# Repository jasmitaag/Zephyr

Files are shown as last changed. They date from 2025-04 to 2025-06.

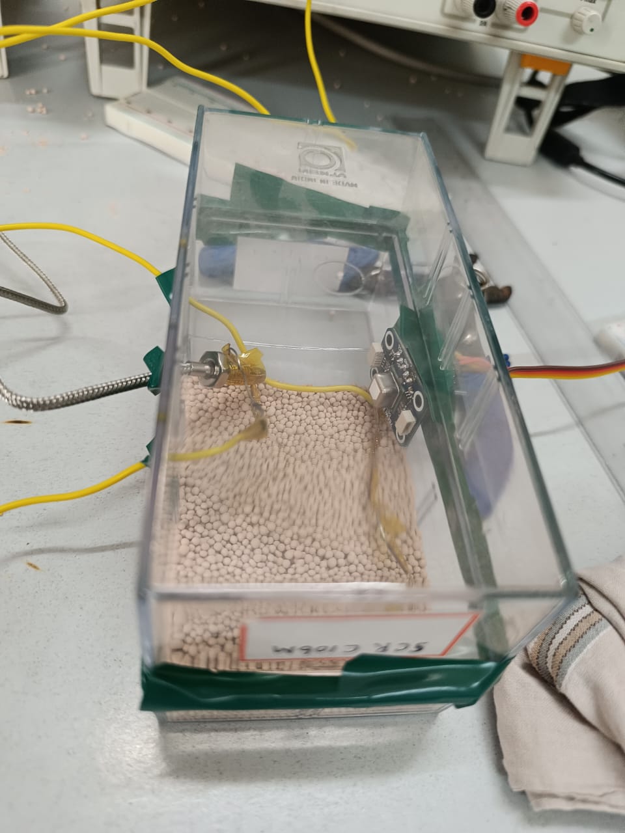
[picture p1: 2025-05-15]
presentations/others/WhatsApp Image 2025-05-08 at 15.26.52_eb9d54cc.jpg

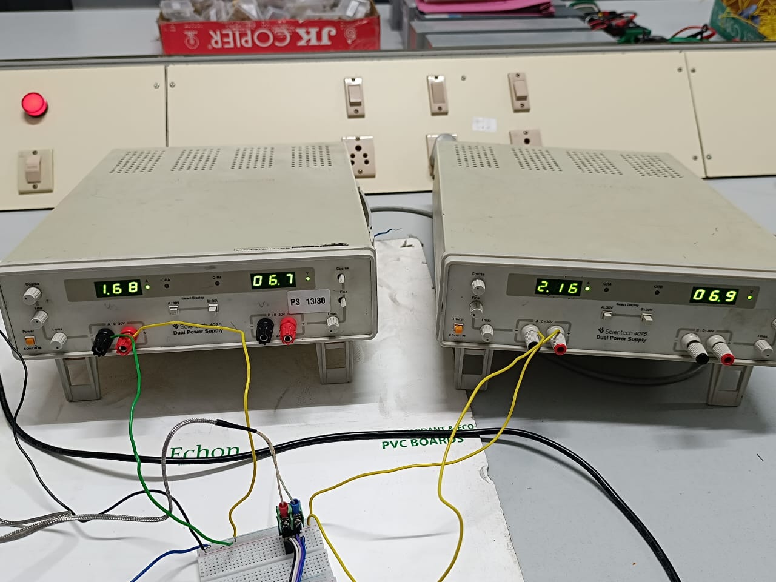
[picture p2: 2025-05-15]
presentations/others/WhatsApp Image 2025-05-07 at 15.44.19_3ac2dfc4.jpg

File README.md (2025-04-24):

# Hybrid Domestic Direct Air Capture (DAC) with Wind Integration

This project is a compact prototype that combines Direct Air Capture (DAC) technology with a small Vertical Axis Wind Turbine (VAWT) to capture CO₂ from ambient air. It uses wind for both mechanical rotation and as an air source for passive CO₂ absorption, minimizing the need for external energy inputs.

## 🌀 Project Overview

- **Type**: Desk-placeable functional prototype
- **Goal**: Demonstrate a low-energy, domestic-scale CO₂ capture system powered by ambient wind
- **Core Components**:
  - 3D-printed VAWT blade with internal chambers
  - Sorbent panel filled with molecular sieves (1.6–2.5 mm)
  - Sliding door mechanism powered by servo motor
  - Thermal regeneration using insulated nichrome wires
  - Central pole for CO₂ gas outlet and wiring transfer
  - Embedded sensors and microcontroller for system monitoring

## 🛠️ Features

- **Hollow Blade Design** with embedded channels for air, wires, and heat insulation
- **Servo Actuator** controls opening and closing of the sorbent chamber
- **Nichrome Wire Heating** system with PWM control for CO₂ desorption
- **Compact Sorbent Panel** with perforated casing and embedded heating
- **Sensor Suite** including temperature, CO₂, and optional airflow sensors

## 🔧 Components Used

| Component | Size (mm) |
|---|---|
| Sorbent Panel | 20 x 20 x 3.5 |
| Molecular Sieves | 1.6–2.5 |
| Servo Motor | 22.6 x 12 x 30 |
| CO₂ Sensor | 50 x 50 x 50 |
| ESP Controller | 50 x 20 x 10 |
| Nichrome Wire | 24 SWG, 2 meters |
| Other Sensors | Up to 100 x 100 x 100 |

## 📦 Files

- `Blade_Model.f3d` – Fusion 360 file for the blade with internal design
- `Sorbent_Panel.f3d` – Sorbent panel CAD model
- `Actuator_Assembly.f3d` – Actuator + bracket + door mechanism
- `Regeneration_Test.ino` – Arduino sketch for PWM-controlled heating test
- `Wiring_Schematic.png` – Heating circuit layout

## 🚀 Getting Started

1. Print components using heat-resistant 3D filament (e.g., HTPLA, PC, or Nylon).
2. Assemble the actuator and mount to the blade panel.
3. Insert sorbent material and nichrome heating element.
4. Use Arduino + MOSFET + 9V transformer for regeneration testing.
5. Monitor temperature near the wire using an analog or digital sensor.

## 🧪 Testing Plan

- Test nichrome heating wire independently to ensure it reaches 100°C
- Validate CO₂ sensor near sorbent panel to check absorption/desorption cycle
- Perform a full system integration test with wind simulation (fan/blower)

## 📌 Notes

- The blade design is intentionally oversized to accommodate wiring and actuators
- Vacuum sealing is approximated using grooves + servo-slide panel
- All electronics are enclosed safely with appropriate insulation

---

Contributions, forks, and feedback welcome!

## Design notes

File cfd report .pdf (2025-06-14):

# BLADE

Prepared by: Jas

Date: Thursday, May 15, 2025

blade.cfdst | Prepared by: Jas
Page 1 | Generated with Autodesk CFD 2026

# Report Contents

Design 1 _____________________________________________________________________________________________________ 2

Decision Center____________________________________________________________________________________________10

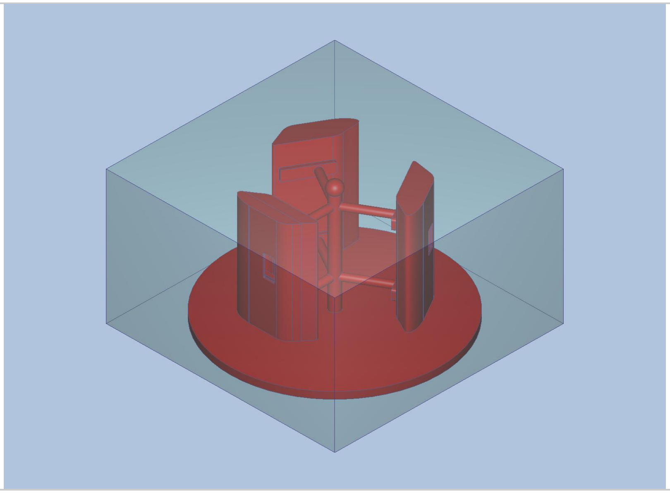
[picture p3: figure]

Page 2 | Generated with Autodesk CFD 2026

# Design 1

Length units | cm
Coordinate system | Cartesian 3D

# SCENARIO 1

# MATERIALS

Page 3 | Generated with Autodesk CFD 2026
NAME | ASSIGNED TO | PROPERTIES
ABS (Polycarbonate) | Part1.Body3_U_Part1.Body2 Part1.Body3 Part1.Body5_U_Part1.Body3 Part1.Body3 Part1.Body4_U_Part1.Body3 Part1.Body3_U_Part1.Body1 | X-Direction 0.181 W/m-K Y-Direction Same as X-dir. Z-Direction Same as X-dir. Density 1.15 g/cm3 Specific heat 1.81 J/g-K Emissivity 0.9 Transmissivity 0.0 Electrical resistivity 1.46e+16 ohm-cm Wall roughness 0.0 meter
Air | CFDCreatedVolume | Density Equation of State Viscosity 1.817e-05 Pa-s Conductivity 0.02563 W/m-K Specific heat 1004.0 J/kg-K Compressibility 1.4 Emissivity 1.0 Wall roughness 0.0 meter Phase Vapor Pressure

# BOUNDARY CONDITIONS

TYPE | ASSIGNED TO
Rotational Velocity(40 RPM {(0,0,0):(0,0,1)}) | Surface:231
Temperature(50 Celsius) | Surface:270 Surface:271 Surface:273 Surface:275
Slip/Symmetry | Surface:270 Surface:271 Surface:273 Surface:275
Pressure(0 Pa Gage) | Surface:272
Velocity Normal(3 m/s) | Surface:274

Page 4 | Generated with Autodesk CFD 2026

# INITIAL CONDITIONS

TYPE | ASSIGNED TO

# MESH

### Automatic Meshing Settings

Surface refinement | True
Gap refinement | True
Resolution factor | 1.0
Edge growth rate | 1.1
Minimum points on edge | 2
Points on longest edge | 10
Surface limiting aspect ratio | 20
Surface growth rate | 1.2
Enhancement growth rate | 1.1
Refinement length | 0.12
Fluid gap elements | 1.0
Thin solid elements | 0.2

### Mesh Enhancement Settings

Mesh enhancement | True
Enhancement blending | False
Number of layers | 3
Layer factor | 0.45
Layer gradation | 1.05

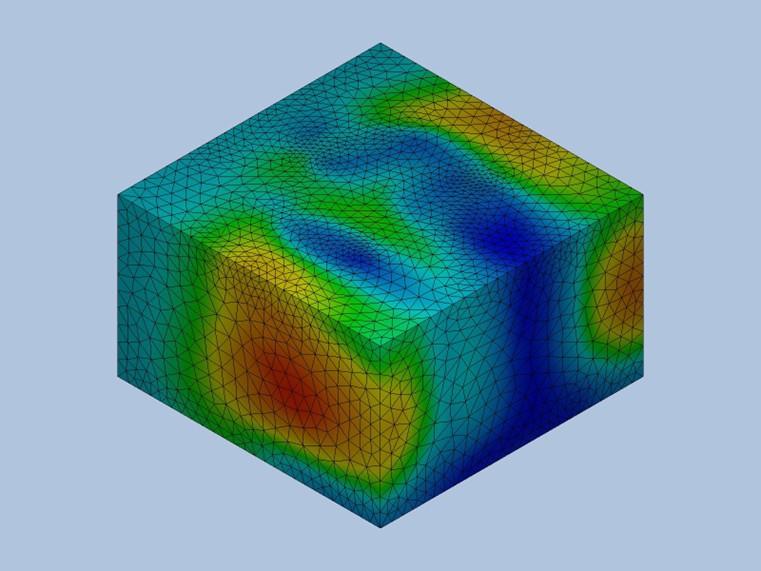
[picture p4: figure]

Page 5 | Generated with Autodesk CFD 2026

### Meshed Model

Number of Nodes | 149158
Number of Elements | 575239

# PHYSICS

Flow | On
Compressibility | Incompressible
Heat Transfer | On
Auto Forced Convection | On
Gravity Components | 0.0, 0.0, 0.0
Radiation | Off
Scalar | No scalar
Turbulence | On

Page 6 | Generated with Autodesk CFD 2026

# SOLVER SETTINGS

Solution mode | Steady State
Solver computer | MyComputer
Intelligent solution control | Off
Advection scheme | ADV 5
Turbulence model | k-epsilon

# CONVERGENCE

Iterations run | 43
Solve time | 317 seconds
Solver version | 26.0.70

### Energy Balance

Fluid Energy Balance Information | (numerical) energy out -3.4562e-12 Watts heat transfer due to sources in 0.0 Watts heat transfer from wall to 3.9482e-15 Watts mdotin x cp x (tout - tin) -5.391e-11 Watts
Solid Energy Balance Information | heat transfer due to sources in 0.0 Watts heat transfer from exterior to 0.0 Watts heat transfer from fluid to -3.9482e-15 Watts

### Mass Balance

IN | OUT
Mass flow | 236.152 g/s | -237.767 g/s
Volume flow | 196020.0 cm^3/s | -197360.0 cm^3/s

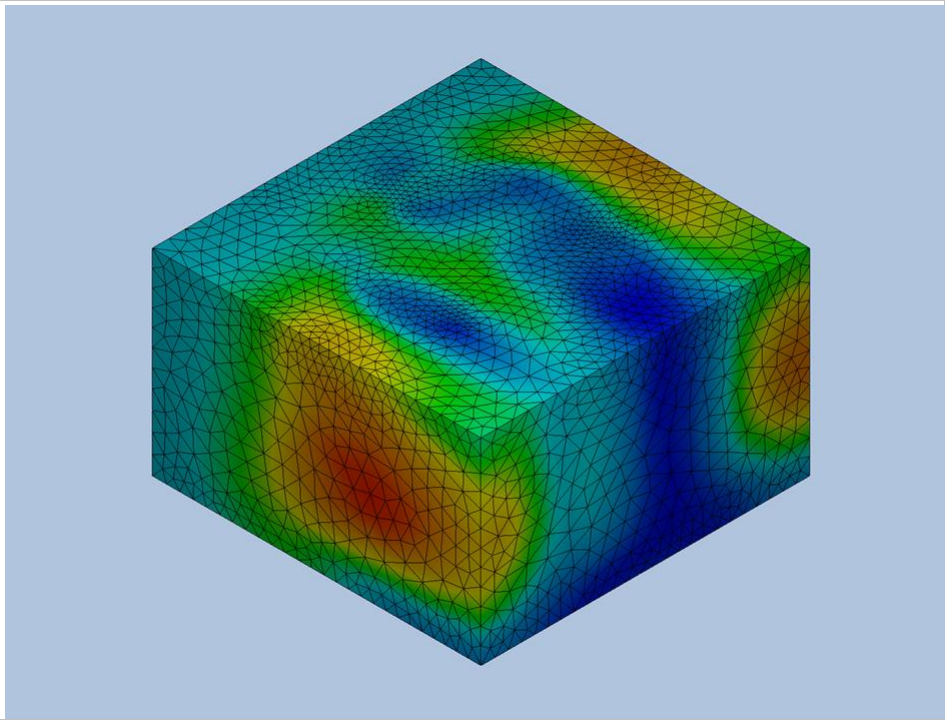
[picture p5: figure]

Page 7 | Generated with Autodesk CFD 2026

# RESULTS

### Inlets and Outlets

inlet 1 | inlet bulk pressure 190.701 dyne/cm^2 inlet bulk temperature 50.0 C inlet mach number 0.00832485 mass flow in 236.152 g/s minimum x,y,z of 0.0 node near minimum 392.0 reynolds number 50844.9 surface id 274.0 total mass flow in 236.152 g/s total vol. flow in 196020.0 cm^3/s volume flow in 196020.0 cm^3/s
outlet 1 | mass flow out -237.767 g/s minimum x,y,z of 0.0 node near minimum 393.0

Page 8 | Generated with Autodesk CFD 2026
outlet bulk pressure | -0.0 dyne/cm^2
outlet bulk | 50.0 C
outlet mach number | 0.00805209
reynolds number | 51192.5
surface id | 272.0
total mass flow out | -237.767 g/s
total vol. flow out | -197360.0 cm^3/s
volume flow out | -197360.0 cm^3/s

### Field Variable Results

VARIABLE | MAX | MIN
cond | 0.00181 W/cm-K | 0.0002563 W/cm-K
dens | 1.15 g/cm^3 | 0.00120473 g/cm^3
econd | 0.474163 W/cm-K | 0.0 W/cm-K
emiss | 1.0 | 0.0
evisc | 0.01817 g/cm-s | 0.0 g/cm-s
gent | 202452.0 1/s | 6.80621e-06 1/s
press | 462.764 dyne/cm^2 | -60.1592 dyne/cm^2
ptotl | 671.338 dyne/cm^2 | -57.7675 dyne/cm^2
scal1 | 0.0 | 0.0
seebeck | 0.0 V/K | 0.0 V/K
shgc | 0.0 | 0.0
spech | 1.81 J/g-K | 1.004 J/g-K
temp | 50.0 C | 50.0 C
transmiss | 0.0 | 0.0
turbd | 49946800000000.0 cm^2/s^3 | 2.21244e-10 cm^2/s^3
turbk | 9677350.0 cm^2/s^2 | 1.83829e-08 cm^2/s^2
ufactor | 0.0 | 0.0
visc | 0.0001817 g/cm-s | 0.0 g/cm-s
vx vel | 1081.68 cm/s | -80.1574 cm/s
vy vel | 297.436 cm/s | -291.217 cm/s
vz vel | 190.432 cm/s | -198.357 cm/s
wrough | 0.0 cm | 0.0 cm

### Component Thermal Summary

PART | MINIMUM
| TEMPERATURE | MAXIMUM TEMPERATURE | VOLUME AVERAGED TEMPERATURE
Part1.Body3_U_Part1.Body2 | 50 | 50 | 50
Part1.Body3 | 50 | 50 | 50
Part1.Body5_U_Part1.Body3 | 50 | 50 | 50
Part1.Body3 | 50 | 50 | 50
Part1.Body4_U_Part1.Body3 | 50 | 50 | 50
Part1.Body3_U_Part1.Body1 | 50 | 50 | 50
CFDCreatedVolume | 50 | 50 | 50

Page 9 | Generated with Autodesk CFD 2026

### Fluid Forces on Walls

pressx | 50059.0 dynes
pressy | -8823.3 dynes
pressz | 31120.0 dynes
shearx | 4754.1 dynes
sheary | -64.769 dynes
shearz | 53.518 dynes

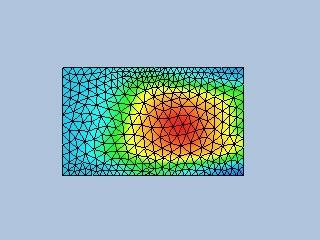
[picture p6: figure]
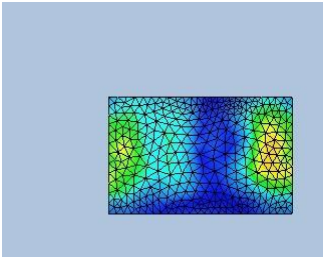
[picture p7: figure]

Page 10 | Generated with Autodesk CFD 2026

# Decision Center

# SUMMARY IMAGES

# IMAGE 01

### Design 1::Scenario 1

# IMAGE 02

### Design 1::Scenario 1

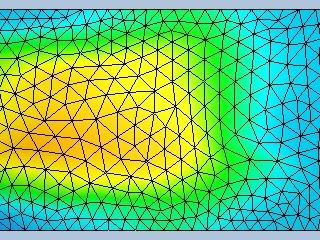
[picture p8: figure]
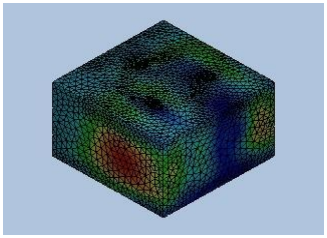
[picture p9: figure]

Page 11 | Generated with Autodesk CFD 2026

# IMAGE 03

### Design 1::Scenario 1

# IMAGE 04

### Design 1::Scenario 1

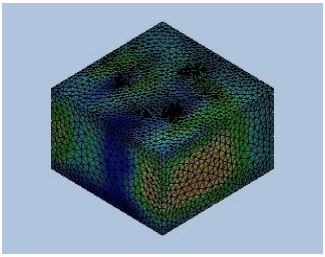
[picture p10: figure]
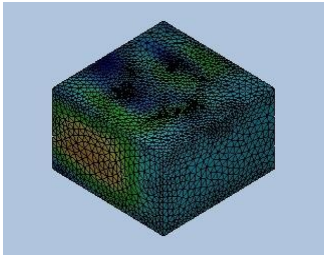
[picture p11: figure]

Page 12 | Generated with Autodesk CFD 2026

# IMAGE 05

### Design 1::Scenario 1

# IMAGE 06

### Design 1::Scenario 1

Page 13 | Generated with Autodesk CFD 2026

# SUMMARY PARTS

# SUMMARY PART 1

RESULT QUANTITY | DESIGN 1::SCENARIO 1
Avg Temperature | 50.0
Max Temperature | 50.0
Min Temperature | 50.0
Volume | 40.8291

# SUMMARY PART 2

RESULT QUANTITY | DESIGN 1::SCENARIO 1
Avg Temperature | 50.0
Max Temperature | 50.0
Min Temperature | 50.0
Volume | 941.711

# SUMMARY PART 7

RESULT QUANTITY | DESIGN 1::SCENARIO 1
Avg Temperature | 50.0
Max Temperature | 50.0
Min Temperature | 50.0
Volume | 20521.1

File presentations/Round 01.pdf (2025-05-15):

# Divya Palanisamy (Lead)

# II year & ECE

# Abithi V B

# II year & CSE

# Jasmitaa G

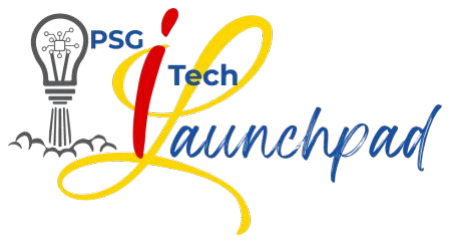
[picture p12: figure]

# II year & ECE

# Dousik Manokaran

# II year & ECE

# 13 - Technique to capture atmospheric CO2

/CO

# Mentor Name

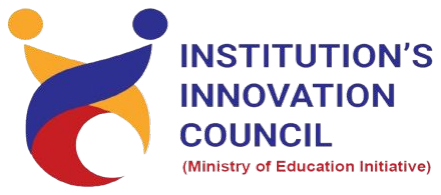
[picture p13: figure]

# Mr. R. RajaRaja ECE

# Technique to capture atmospheric CO2

/CO

# Aim

❖ To develop an innovative solution that integrates Direct Air Capture (DAC) technology with wind turbines, harnessing renewable wind energy to efficiently capture and reduce atmospheric CO₂ levels, contributing to climate change mitigation and advancing sustainable energy practices.

# Objectives

## ❖ The primary objectives of the project includes:

– To create a practical prototype that is not easily confined by geographical boundaries.
– To create an effective system for taking in ambient air while saving a considerable amount of energy from air contactor fans.

## – To integrate our project with existing technology to minimize substantial downtime and

maintenance concerns that new technologies may encounter.

# ❖ A technique to capture CO2

/CO from the air, helping mitigate climate change. ❖ Currently, we rely on Direct Air Capture (DAC) Technologies to achieve negative emissions.

# ❖ However, these technologies are generally constrained by:

– Expense: Spending on some DAC plants currently reaps less return than other alternatives.
– Concentration: Systems must process huge volumes of air to capture relatively modest levels of CO2 in air [0.04% or 400 ppm in ambient air].
– Energy: Approximately 5.92 GJ of energy is required to remove on ton of CO2.
– Location: To achieve net zero emissions, the system must be physically close to renewable sources.

# 1. Problem Statement

Step | Type | Energy Required (GJ/t CO2 )
Air contactor fans | Electrical | 0.55-1.12
Vacuum Pump | Electrical | (110-140) x 10⁻⁴
Desorption Heat | Thermal | 3.4-4.8

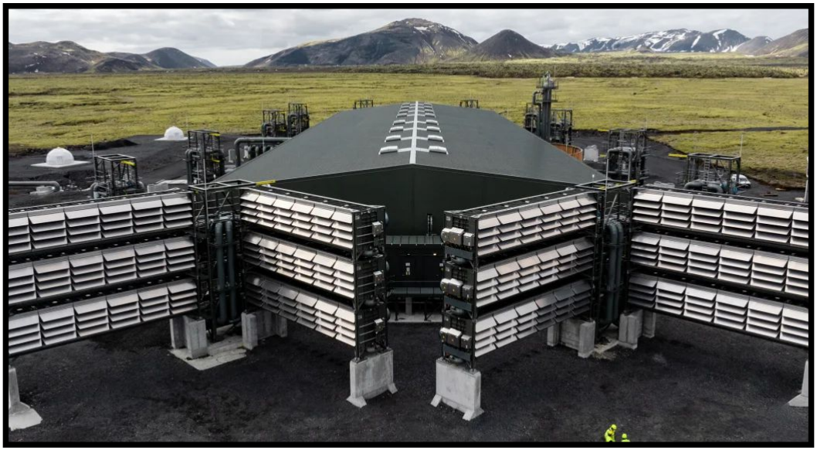
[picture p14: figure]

Mammoth: our newest direct air capture and storage facility (https://climeworks.com/plant-mammoth) | National Academics (https://nap.nationalacademies.org/read/25259/chapter/7#194)

# 2. Existing Technology Overview

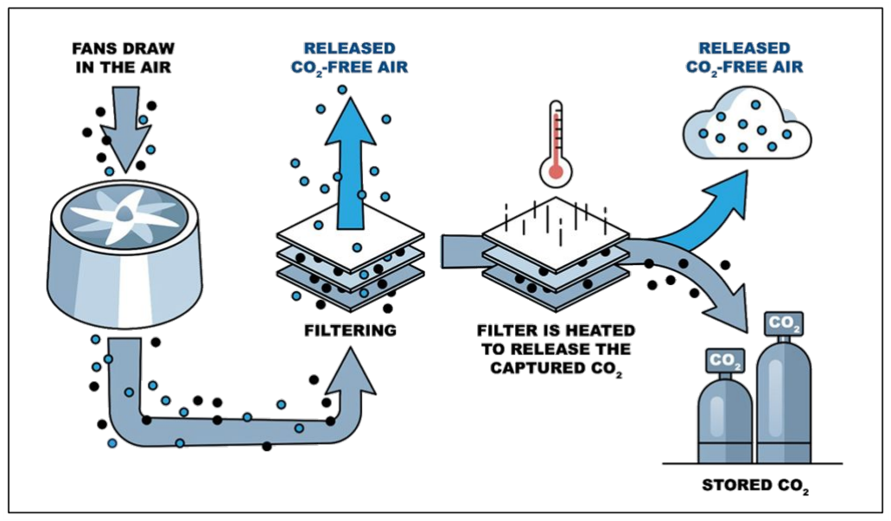
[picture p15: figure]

Flowchart (https://climeworks.com/plant-mammoth)

# 3. Innovation - Conceptual Flowchart

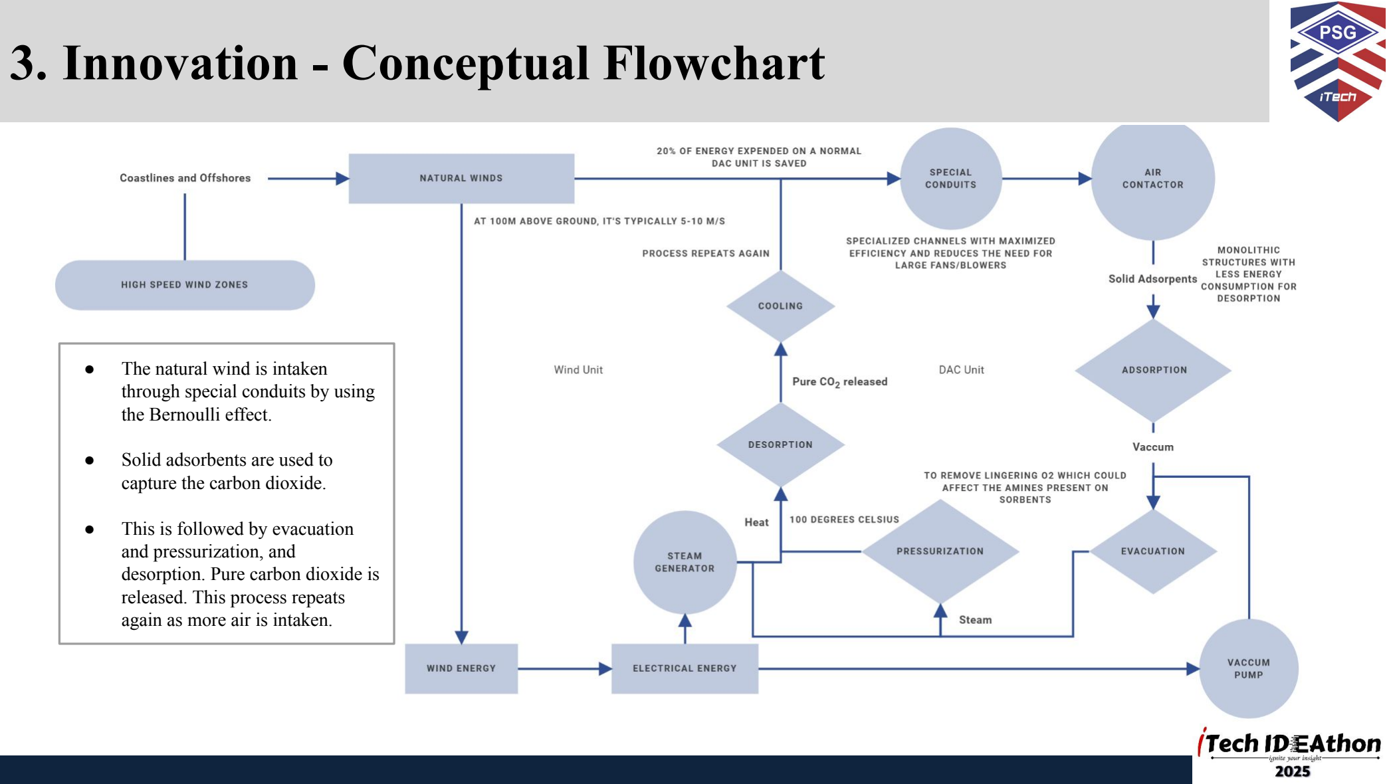
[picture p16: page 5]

- The natural wind is intaken through special conduits by using the Bernoulli effect.
- Solid adsorbents are used to capture the carbon dioxide.
- This is followed by evacuation and pressurization, and
desorption. Pure carbon dioxide is released. This process repeats again as more air is intaken.

# 3. Innovation

Category | Key Features | Benefits
Land Use | DAC integrated with windmills eliminates the need for additional land. | Optimized land utilization.
Energy Efficiency | Utilizes windmills’ electricity and heat energy directly for DAC operations. | Prevents energy wastage by using surplus power for CO₂ removal.
Natural Airflow Advantage | High-speed wind zones enable direct air intake via ducts (Bernoulli effect). | Reduces fan energy requirements, cutting operational costs by ~ 20%.
Solid Sorbents Over Liquids | Requires less thermal energy compared to liquid sorbents. | Enhances energy efficiency and scalability for large-scale deployment.
Economic and Environmental Impact | Wind energy is a carbon-neutral power source. | High CO₂ removal potential with reduced environmental footprint.
Cost Reduction Strategies | Shared infrastructure between DAC and windmills lowers initial costs. | Mass production of small DAC units across wind farms further reduces costs.

# 4. Technicalities and Scope

### ❖ Technical Feasibility of DAC with Wind Energy in India:

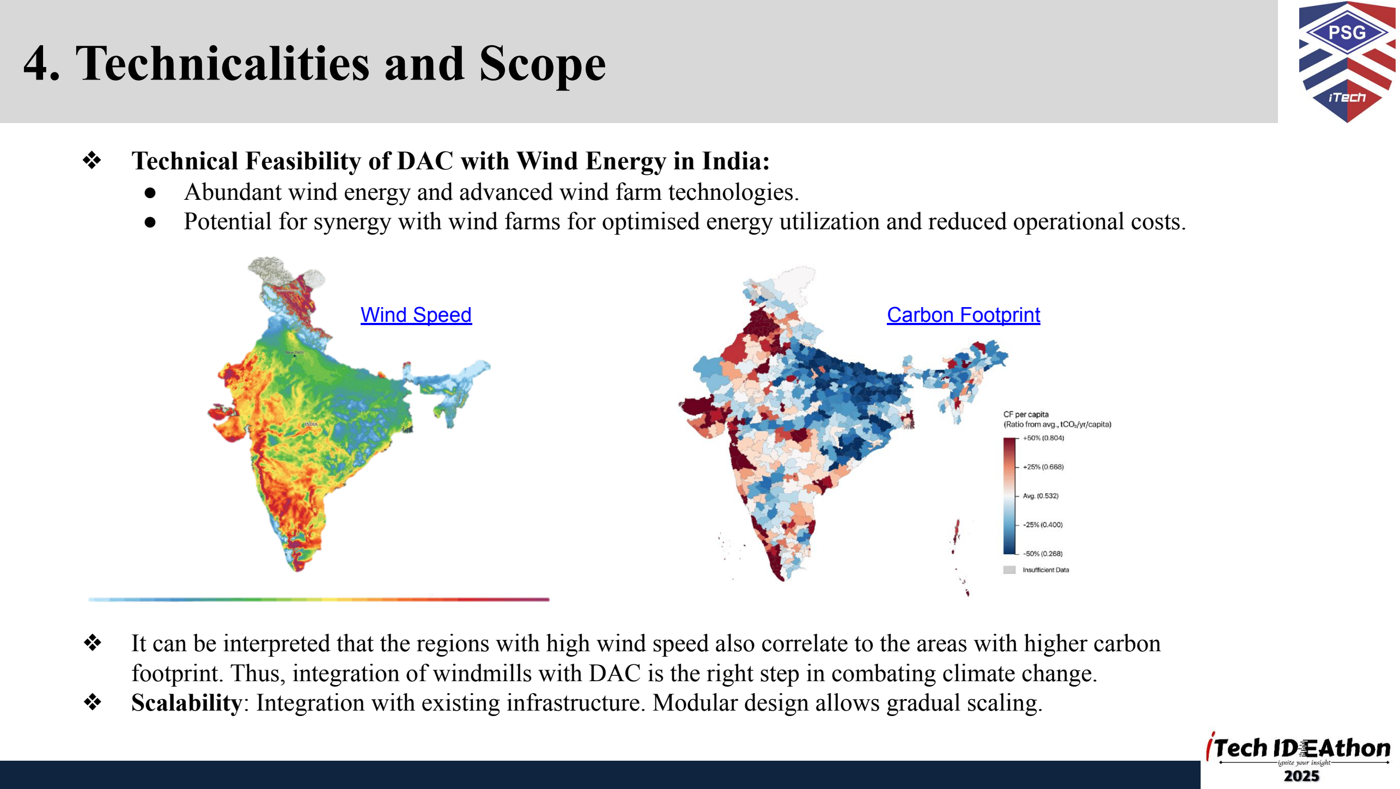
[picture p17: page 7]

❖ It can be interpreted that the regions with high wind speed also correlate to the areas with higher carbon footprint. Thus, integration of windmills with DAC is the right step in combating climate change.
❖ Scalability: Integration with existing infrastructure. Modular design allows gradual scaling.
Wind Speed (https://globalwindatlas.info/en/) | Carbon Footprint (https://www.researchgate.net/figure/Carbon-footprints-per-capita-in-623-districts-in-India-Choropleth-map-showing-the_fig2_347625606)
- Abundant wind energy and advanced wind farm technologies.
- Potential for synergy with wind farms for optimised energy utilization and reduced operational costs.

❖ Currently, most of the existing DAC units inject CO2 back into geological formations. This is an expensive process, and detriments efficiency and capacity of the units.
❖ As an alternative, we propose to meet the demand for carbon dioxide in several industries, by

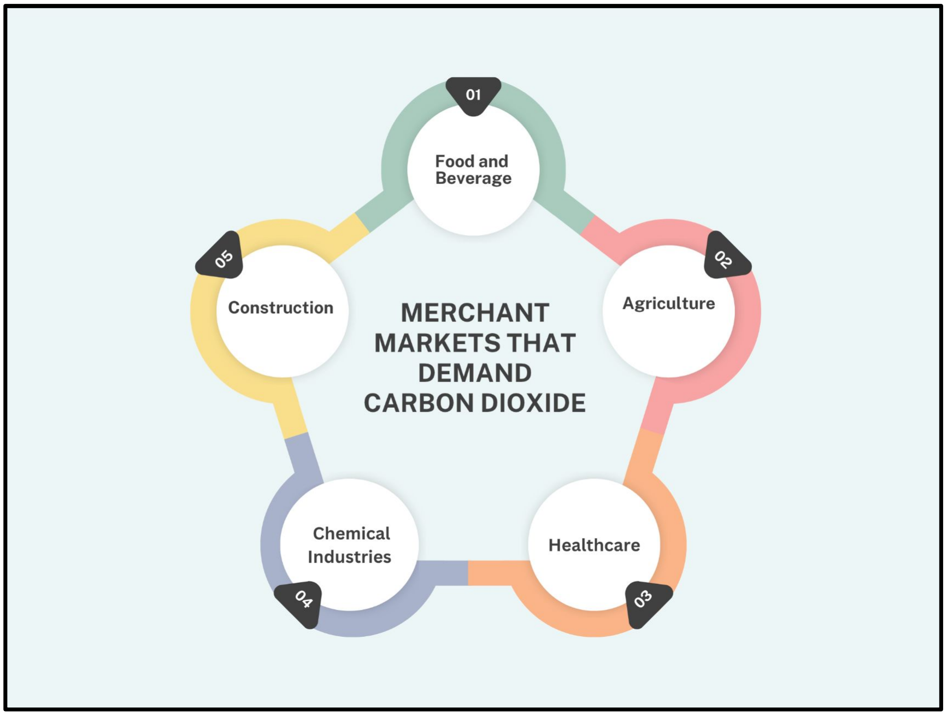
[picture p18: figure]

supplying the captured CO2 to them.

# ❖ Benefits:

## – Supply Reliability

- Consistent supply of carbon dioxide.

## – Sustainability

- Scalable source of CO2 that aligns with net-zero goals.

## – Circular Economy - The system involves capture, use and recycling of CO2

- This reduces overall environmental impact.

# 5. Target Audience/Market

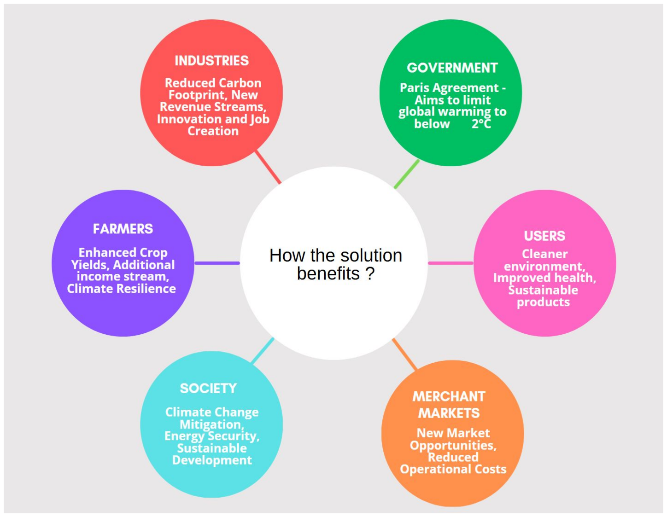
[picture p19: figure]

# ❖ Carbon capture, utilization, and storage

# (CCUS) is a powerful tool for a

sustainable future.

# ❖ Lower carbon footprint in industries

reduces greenhouse gas emissions, improves air quality.

# ❖ By capturing and storing CO2 , CCUS mitigates climate change and fortifies

energy security.

# ❖ Industries, farmers, and society as a whole

benefit from CCUS.

# 6. Social/Environmental Impact

# 7. Financials

Components | Cost Ranges | Technical Part Names
Sorbent Material, Support Structure and Mechanical Regeneration System | ₹4,500 - ₹10,000 | Activated Carbon (AC), Zeolite (ZE), Metal-Organic Frameworks (MOF)
AC Generator | ₹5,000 - ₹10,000 | Small Permanent Magnet Generator AC
| | Alternator
Sensors | ₹2,500 - ₹5,500 | CO2 Sensor (MH-Z19), Pressure Sensor (BMP180)
Control Systems | ₹1,000 - ₹2,500 | Arduino Uno Microcontroller (ATmega328P) Miscellaneous Electronics (Wirings, Connectors)
Actuators | ₹2,500 - ₹5,500 | Linear Actuator (LA-14), Rotary Actuator (RA-25)
Pneumatic Cylinders | ₹2,000 - ₹4,500 | SMC Compact Cylinder (CQ2B Series)
Total | ₹17,500 - ₹38,500 | -

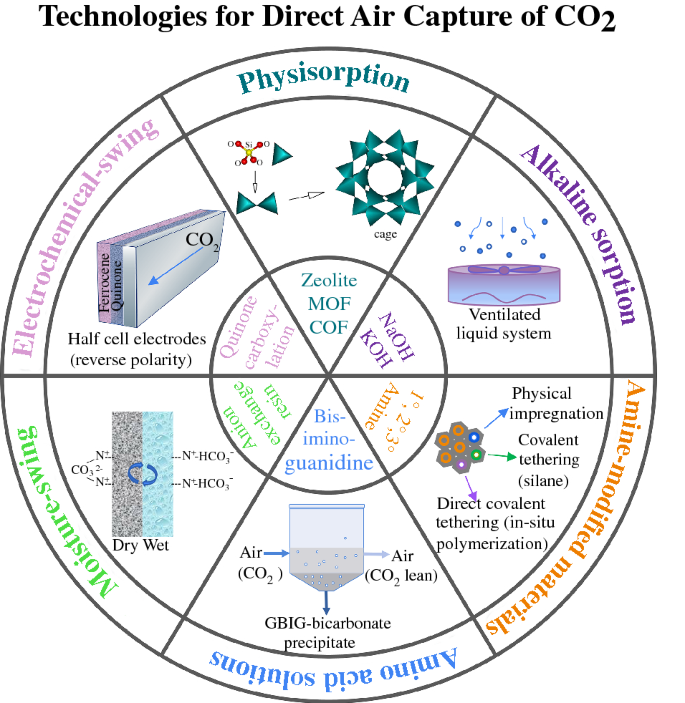
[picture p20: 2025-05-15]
research/43577_2022_320_Figa_HTML.png

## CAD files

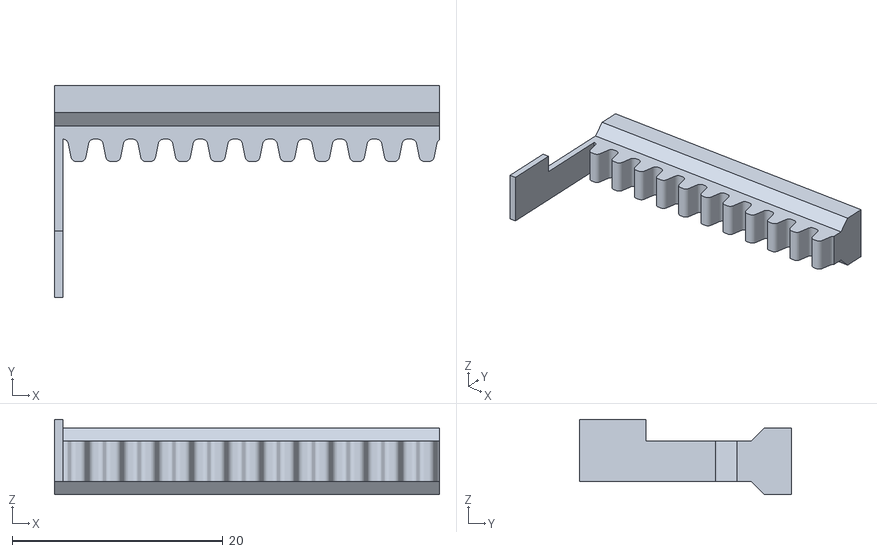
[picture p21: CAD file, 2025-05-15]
hardware/stl/pusher.stl
36.5 x 20.1 x 7.15

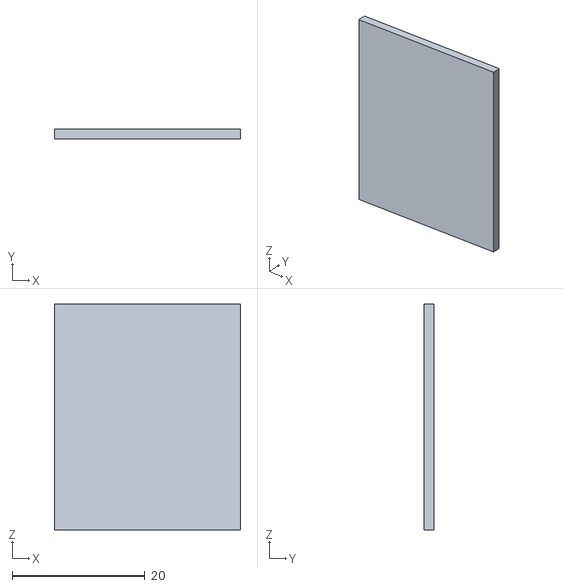
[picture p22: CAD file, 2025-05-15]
hardware/stl/door.stl
28.0 x 1.50 x 34.0

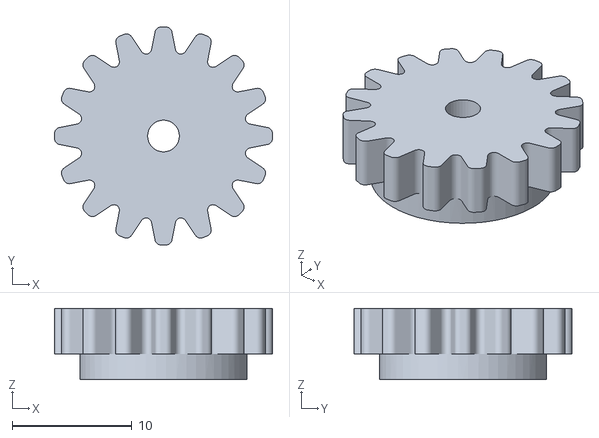
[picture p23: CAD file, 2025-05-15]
hardware/stl/pinion.stl
18.2 x 18.2 x 5.97

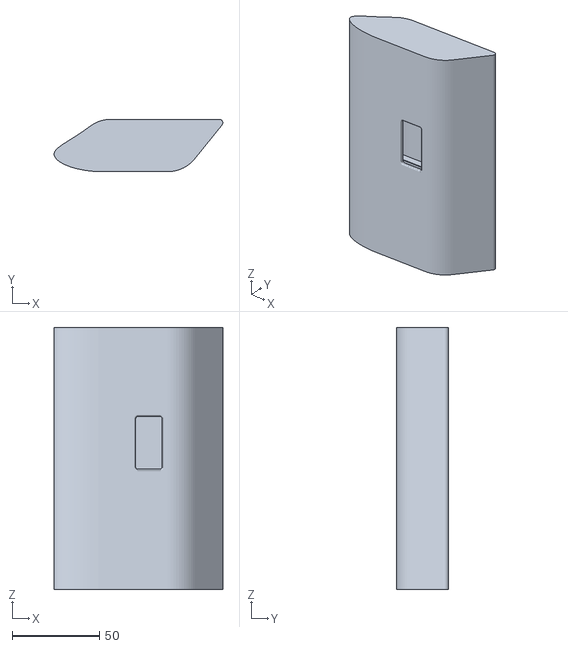
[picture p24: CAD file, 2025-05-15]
hardware/stl/prototype.stl
96.6 x 30.0 x 150.0

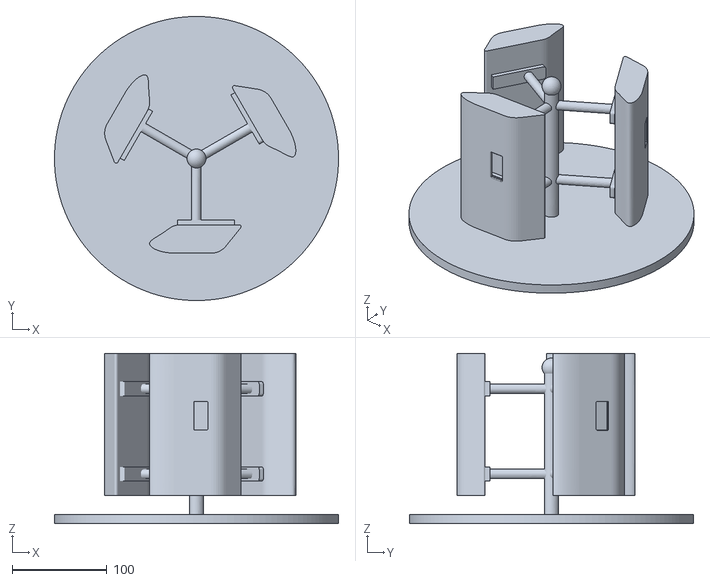
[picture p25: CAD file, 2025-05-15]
hardware/stl/final.stl
300.0 x 299.9 x 180.0

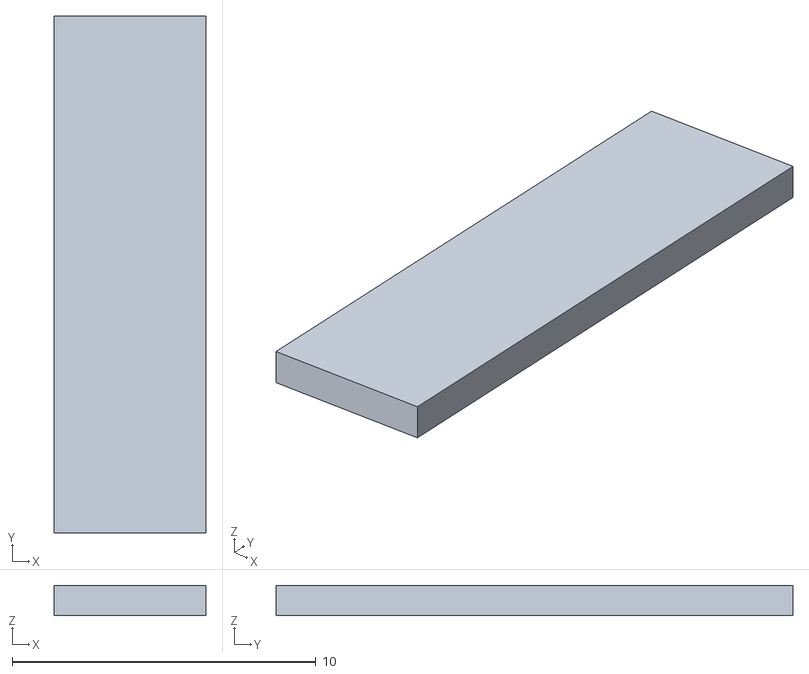
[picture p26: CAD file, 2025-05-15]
hardware/stl/panel.stl
5.00 x 17.0 x 1.00

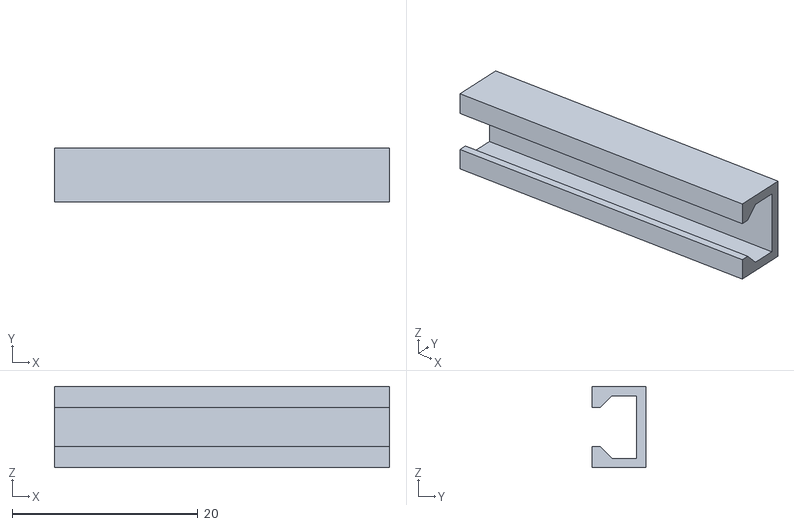
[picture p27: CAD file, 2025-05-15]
hardware/stl/pusher_bracket.stl
36.1 x 5.85 x 8.74

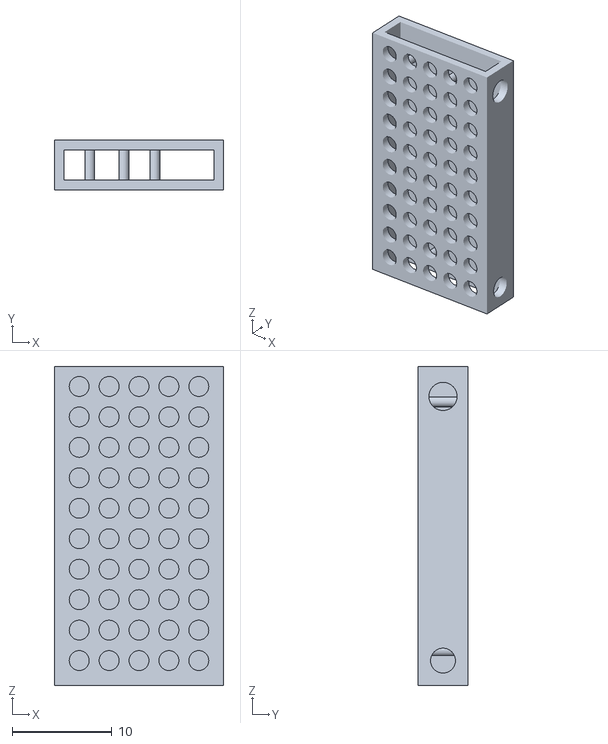
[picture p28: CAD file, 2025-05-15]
hardware/stl/sorbent_panel.stl
17.0 x 5.00 x 32.0

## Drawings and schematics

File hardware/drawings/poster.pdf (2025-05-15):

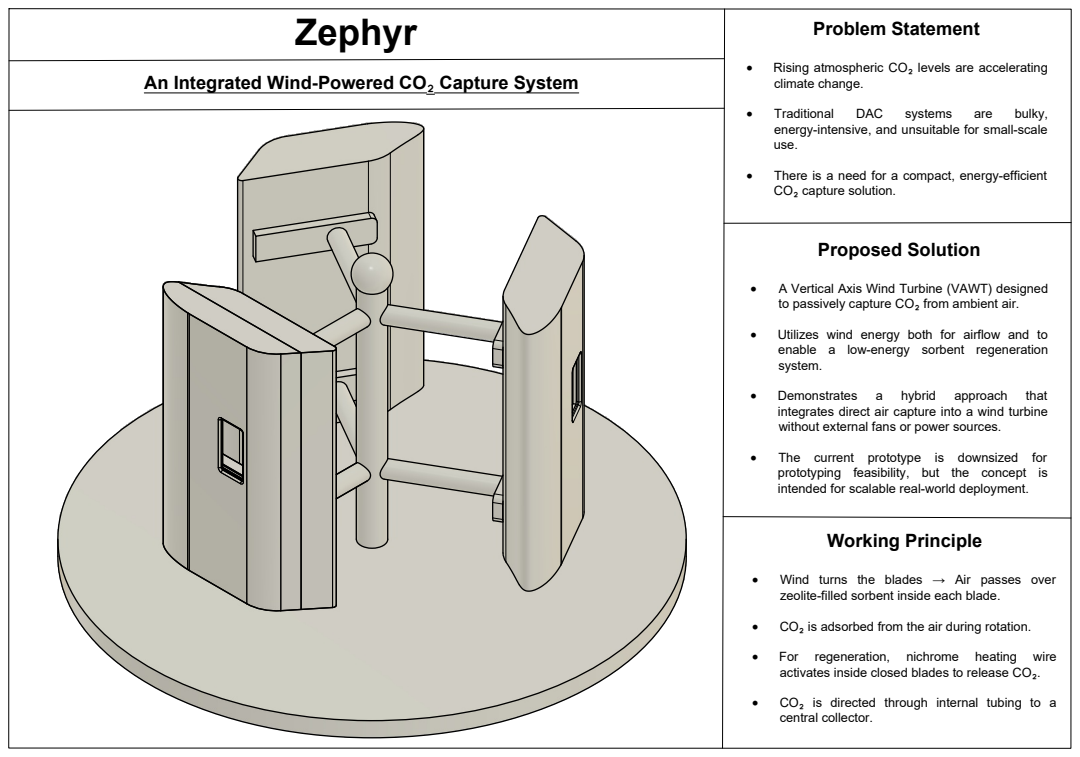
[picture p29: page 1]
Problem Statement; Proposed Solution; Working Principle; activates inside closed blades to release CO₂. ·; CO₂ is directed through internal tubing to a; central collector.

· Rising atmospheric CO₂ levels are accelerating
climate change.

An Integrated Wind-Powered CO₂ Capture System

energy-intensive, and unsuitable for small-scale
use.

· There is a need for a compact, energy-efficient
CO₂ capture solution.

· A Vertical Axis Wind Turbine (VAWT) designed
to passively capture CO₂ from ambient air.

· Utilizes wind energy both for airflow and to
enable a low-energy sorbent regeneration
system.

integrates direct air capture into a wind turbine
without external fans or power sources.

· The current prototype is downsized for
prototyping feasibility, but the concept is
intended for scalable real-world deployment.

· Wind turns the blades → Air passes over
zeolite-filled sorbent inside each blade.

· CO₂ is adsorbed from the air during rotation.

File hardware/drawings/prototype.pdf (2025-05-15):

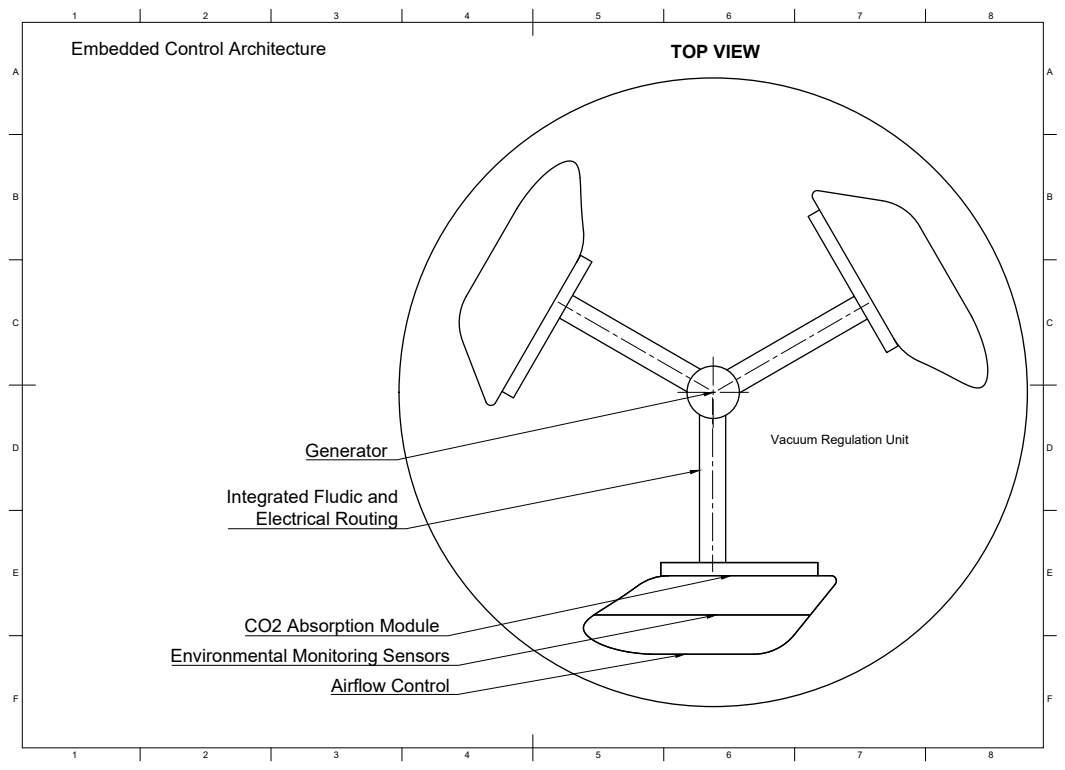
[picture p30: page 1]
Airflow Control; CO2 Absorption Module; Embedded Control Architecture; TOP VIEW

Vacuum Regulation Unit Generator

Integrated Fludic and
Electrical Routing

Environmental Monitoring Sensors

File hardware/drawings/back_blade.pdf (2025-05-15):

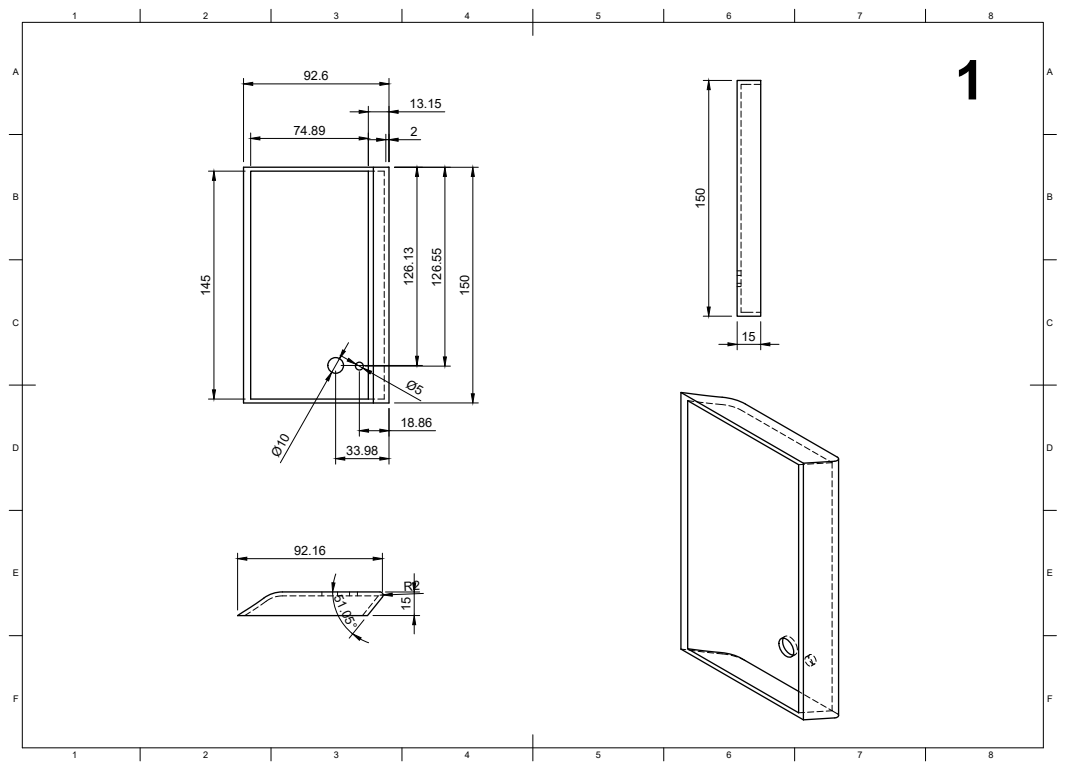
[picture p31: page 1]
8 BCDEF; ABCDEF 150

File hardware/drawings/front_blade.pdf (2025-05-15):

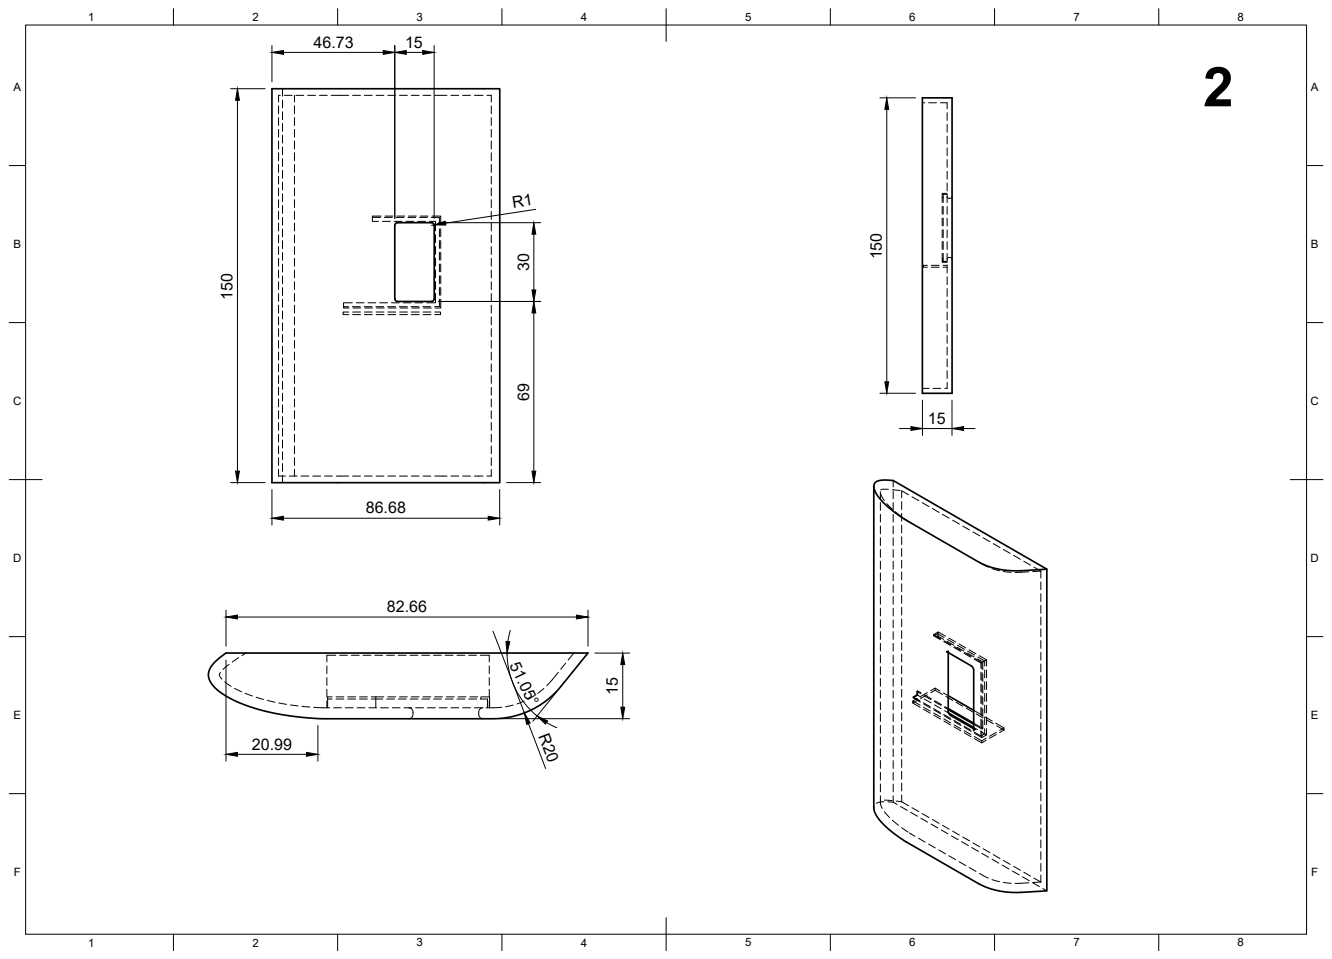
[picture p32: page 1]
8 BCDEF; ABCDEF 150

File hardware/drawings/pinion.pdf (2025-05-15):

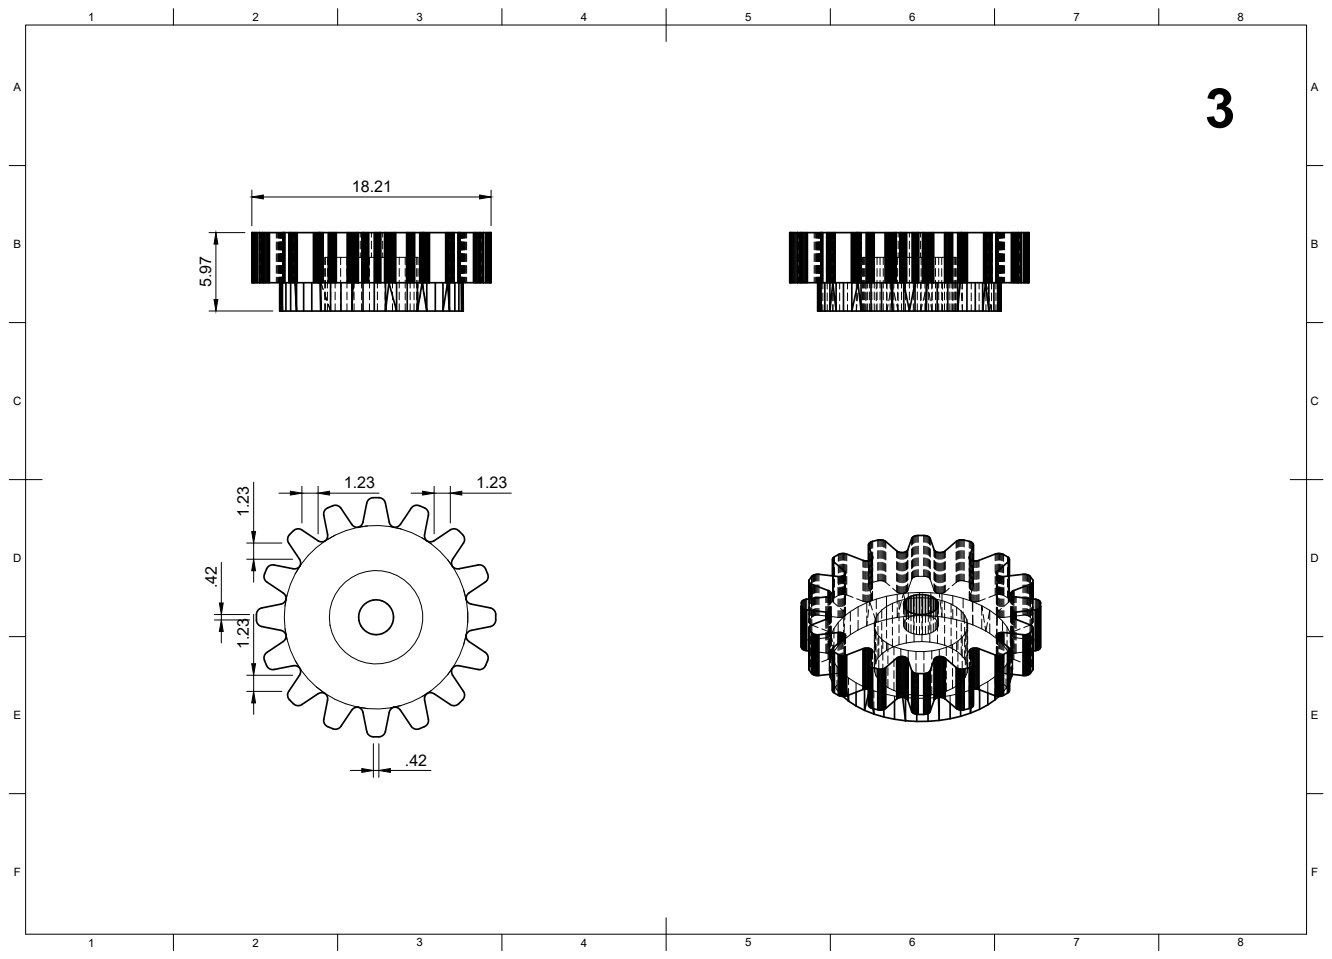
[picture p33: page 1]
8 BCDEF; ABCDEF

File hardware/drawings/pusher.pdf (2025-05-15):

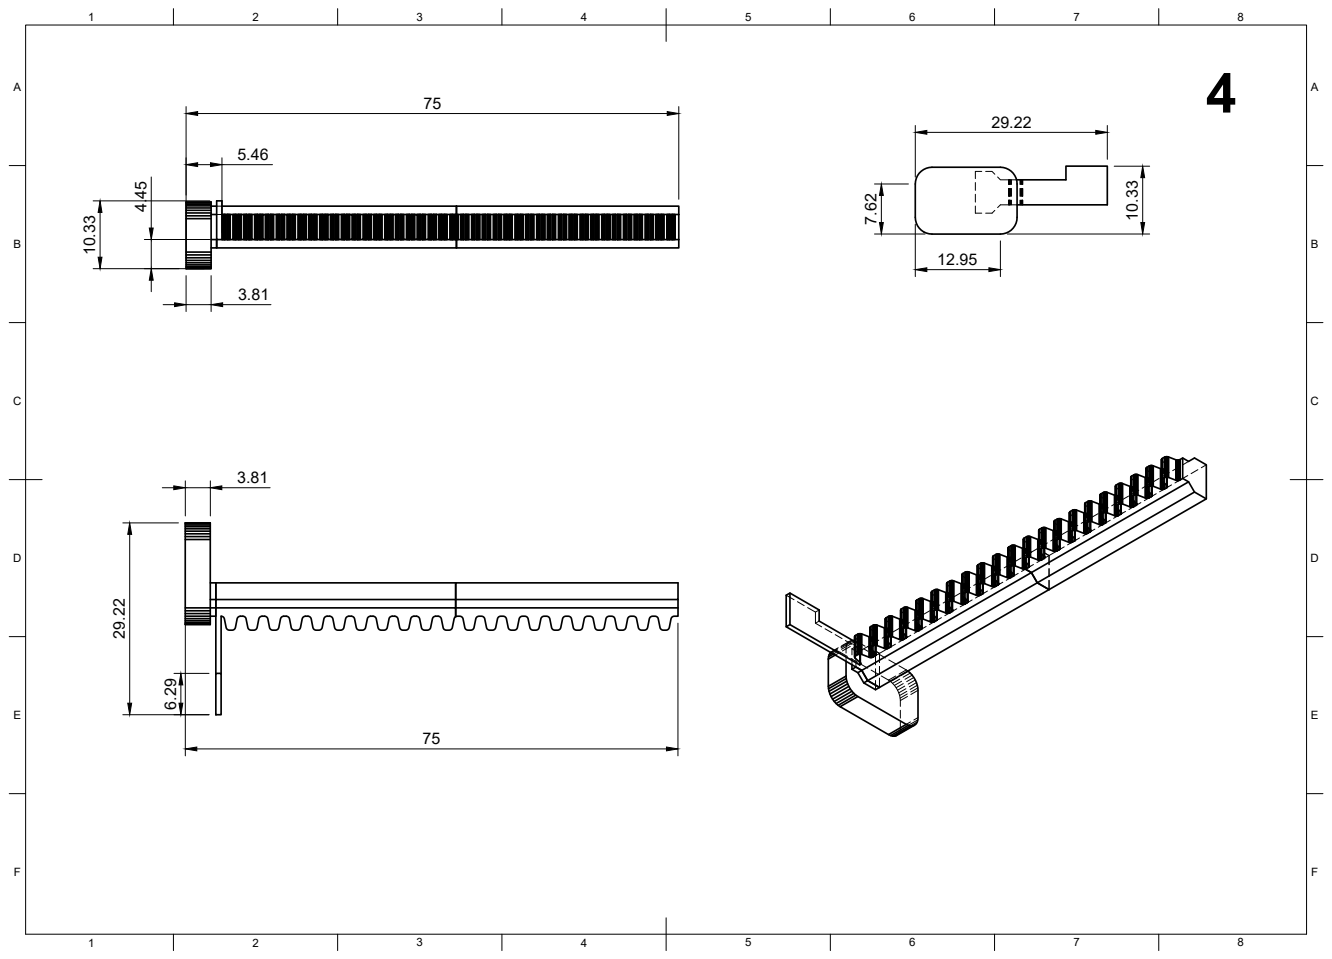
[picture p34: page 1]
8 BCDEF; ABCDEF

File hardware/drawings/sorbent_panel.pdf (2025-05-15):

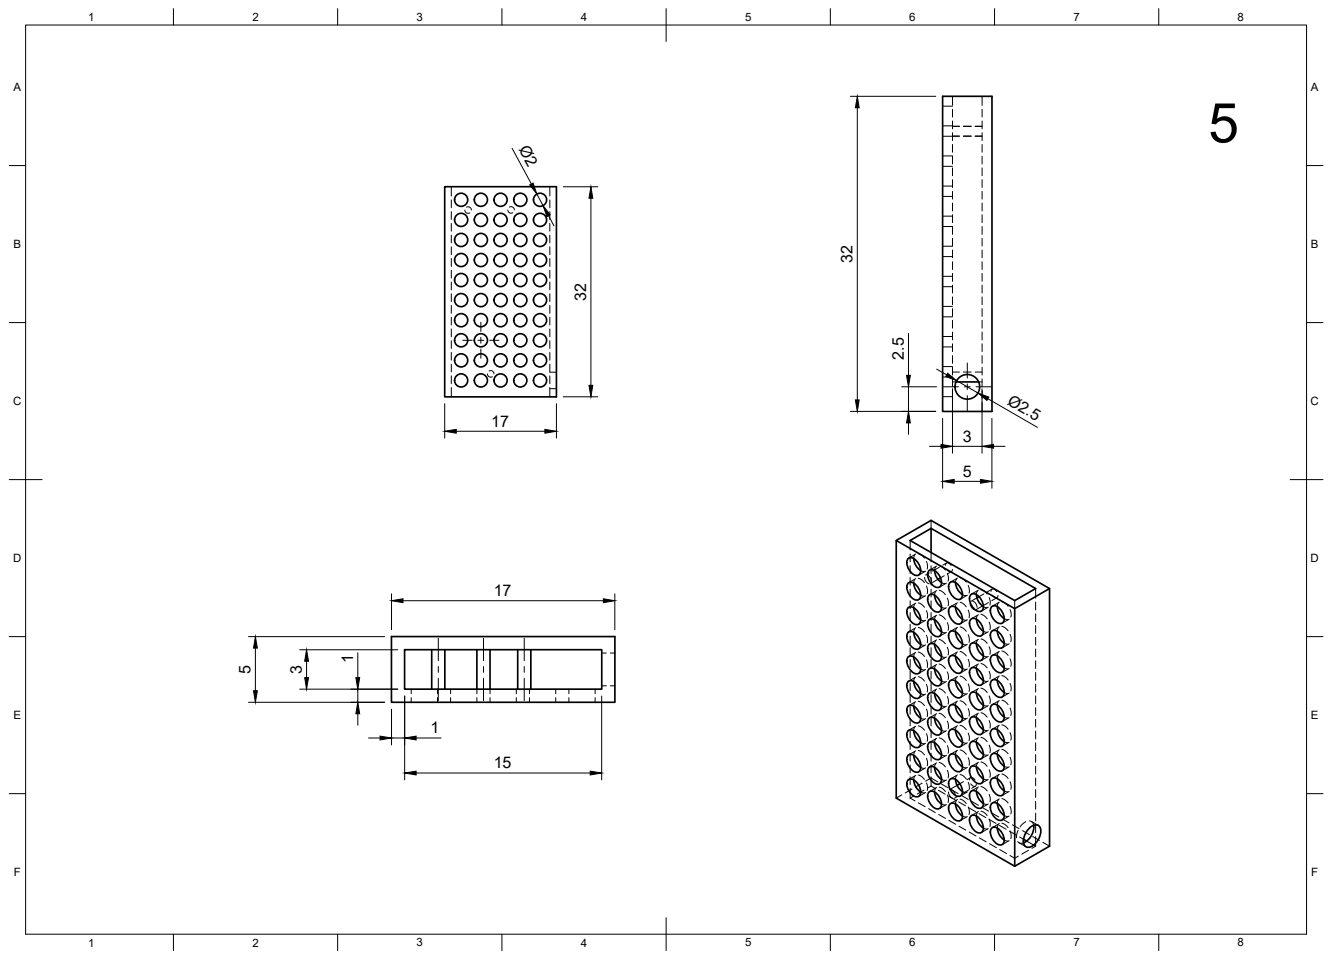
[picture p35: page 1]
8 BCDEF; ABCDEF 32

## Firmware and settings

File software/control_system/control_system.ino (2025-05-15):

#include <Arduino.h>
#include <Wire.h>
#include <SensirionI2cScd4x.h>
#include <max6675.h>

// CO2 Sensor Definitions
SensirionI2cScd4x scd4x;
static char errorMessage[64];
static int16_t error;

// MAX6675 Thermocouple Definitions
const int thermoSO = 8;    // SO = Data Out
const int thermoCS = 9;    // CS = Chip Select
const int thermoSCK = 10;  // SCK = Serial Clock
MAX6675 thermocouple(thermoSCK, thermoCS, thermoSO);

// Relay Control
const int relayPin = 4;
const float tempLow = 36;   // Turn heater ON below this
const float tempHigh = 41; // Turn heater OFF above this
static bool heaterOn = false;

// CO2 Sensor Macros
#ifdef NO_ERROR
#undef NO_ERROR
#endif
#define NO_ERROR 0

void PrintUint64(uint64_t& value) {
    Serial.print("0x");
    Serial.print((uint32_t)(value >> 32), HEX);
    Serial.print((uint32_t)(value & 0xFFFFFFFF), HEX);
}

void setup() {
    Serial.begin(9600);
    while (!Serial) {
        delay(100);
    }

    // Initialize I2C and CO2 Sensor
    Wire.begin();
    scd4x.begin(Wire, SCD41_I2C_ADDR_62);

    uint64_t serialNumber = 0;
    delay(30);
    error = scd4x.wakeUp();
    scd4x.stopPeriodicMeasurement();
    scd4x.reinit();

    error = scd4x.getSerialNumber(serialNumber);
    if (error != NO_ERROR) {
        Serial.print("Error getting serial number: ");
        errorToString(error, errorMessage, sizeof errorMessage);
        Serial.println(errorMessage);
    } else {
        Serial.print("SCD4x serial number: ");
        PrintUint64(serialNumber);
        Serial.println();
    }

    error = scd4x.startPeriodicMeasurement();
    if (error != NO_ERROR) {
        Serial.print("Error starting periodic measurement: ");
        errorToString(error, errorMessage, sizeof errorMessage);
        Serial.println(errorMessage);
    }

    // Initialize Relay Control
    pinMode(relayPin, OUTPUT);
    digitalWrite(relayPin, LOW); // Assume LOW = heater OFF
    delay(500); // Thermocouple stabilization
}

void loop() {
    // Wait 5 seconds
    delay(5000);

    // --- CO2 Sensor Readings ---
    bool dataReady = false;
    error = scd4x.getDataReadyStatus(dataReady);
    if (error != NO_ERROR) {
        Serial.println("Error checking data ready");
        return;
    }

    while (!dataReady) {
        delay(100);
        error = scd4x.getDataReadyStatus(dataReady);
        if (error != NO_ERROR) {
            Serial.println("Error polling data ready");
            return;
        }
    }

    uint16_t co2 = 0;
    float temp = 0.0;
    float rh = 0.0;
    error = scd4x.readMeasurement(co2, temp, rh);
    if (error == NO_ERROR) {
        Serial.print("CO2 [ppm]: ");
        Serial.print(co2);
        Serial.print(" | Temp [°C]: ");
        Serial.print(temp);
        Serial.print(" | RH [%]: ");
        Serial.println(rh);
    } else {
        Serial.println("Error reading CO2 sensor data");
    }

    // --- Thermocouple Heater Control ---
    float heaterTemp = thermocouple.readCelsius();
    Serial.print("Thermocouple Temp: ");
    Serial.print(heaterTemp);
    Serial.print(" °C | Heater: ");

    if (heaterTemp < tempLow && !heaterOn) {
        digitalWrite(relayPin, HIGH);  // Turn heater ON (active-high or -low depending on module)
        heaterOn = true;
        Serial.println("ON");
    } else if (heaterTemp > tempHigh && heaterOn) {
        digitalWrite(relayPin, LOW);  // Turn heater OFF
        heaterOn = false;
        Serial.println("OFF");
    } else {
        Serial.println(heaterOn ? "ON" : "OFF");
    }
}

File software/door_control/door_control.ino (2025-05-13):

#include <ESP32Servo.h>

Servo myServo;
int buttonPin = 2;

int lastButtonState = HIGH;
int currentButtonState;
unsigned long lastDebounceTime = 0;
unsigned long debounceDelay = 50;

int state = 0;  // 0: Stop, 1: Open, 2: Stop, 3: Close

void setup() {
  Serial.begin(115200);
  myServo.attach(4);  // Servo on pin 9
  pinMode(buttonPin, INPUT_PULLUP);  // Button connected to GND
  myServo.writeMicroseconds(1500);  // Initial stop
  Serial.println("Initialized. State 0: Stop");
}

void loop() {
  int reading = digitalRead(buttonPin);

  // Debounce check
  if (reading != lastButtonState) {
    lastDebounceTime = millis();
  }

  if ((millis() - lastDebounceTime) > debounceDelay) {
    if (reading == LOW && currentButtonState == HIGH) {
      state = (state + 1) % 4;  // Cycle: 0 → 1 → 2 → 3 → 0 ...

      switch (state) {
        case 0:
          myServo.writeMicroseconds(1500);  // Stop
          Serial.println("State 0: Stop");
          break;
        case 1:
          myServo.writeMicroseconds(1725);  // Slow CW (Open)
          Serial.println("State 1: Opening (slow CW)");
          break;
        case 2:
          myServo.writeMicroseconds(1500);  // Stop
          Serial.println("State 2: Stop");
          break;
        case 3:
          myServo.writeMicroseconds(1300);  // Slow CCW (Close)
          Serial.println("State 3: Closing (slow CCW)");
          break;
      }
    }
    currentButtonState = reading;
  }

  lastButtonState = reading;
}

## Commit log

2025-04-24 Create scd40.ino
    Test program for the SCD40 CO2 Sensor
2025-05-08 Added relay test code
2025-05-08 Added relay+max6675 control code
2025-05-15 Final Update
    All presentations, hardware files, software codes and others have been uploaded.
    [door.stl, final.stl, panel.stl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]
